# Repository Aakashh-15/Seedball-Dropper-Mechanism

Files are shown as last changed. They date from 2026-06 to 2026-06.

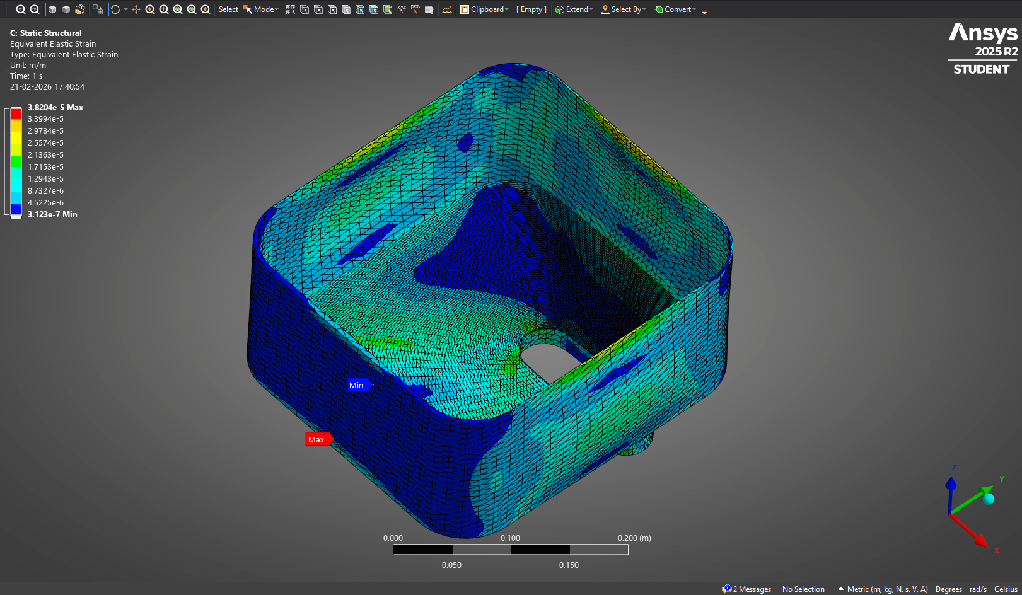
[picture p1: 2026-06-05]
04_ANALYSIS/equivalent_strain.png

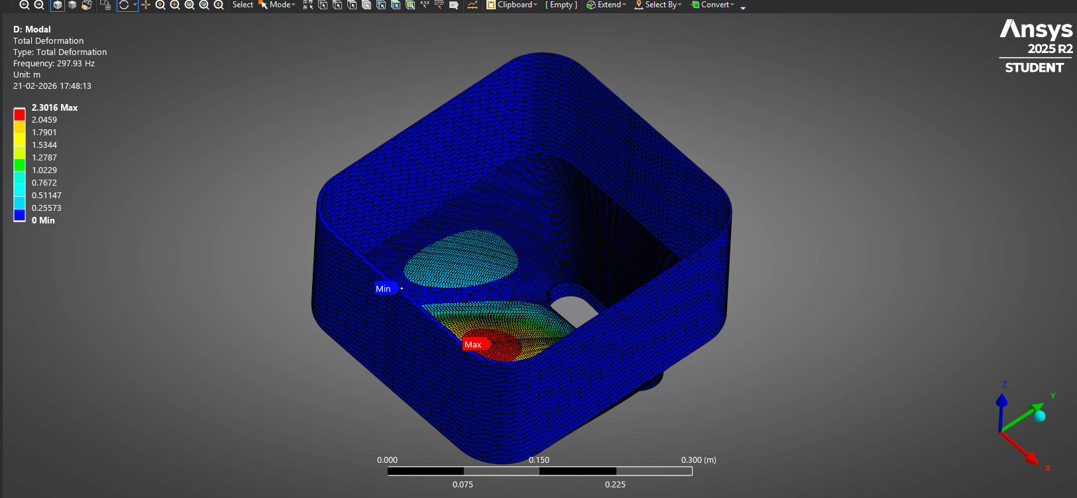
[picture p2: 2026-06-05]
04_ANALYSIS/modal.png

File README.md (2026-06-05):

# 🚁 Autonomous Seedball Dispensing System — Kriti 2026 Drone Design Challenge

> **A complete UAV-mounted autonomous seedball dispensing payload** designed for precision aerial reforestation. This repository contains the complete design, analysis, electronics, and simulation framework.

---

## 📋 Table of Contents

1. [Project Overview](#project-overview)
2. [System Architecture](#system-architecture)
3. [Repository Structure](#repository-structure)
4. [Component Breakdown](#component-breakdown)
5. [Key Deliverables](#key-deliverables)
6. [Quick Links to Subdirectories](#quick-links-to-subdirectories)
7. [Results & Performance](#results--performance)
8. [Team & Attribution](#team--attribution)

---

## 🎯 Project Overview

Modern aerial reforestation requires reliable deployment of irregular seedballs across remote terrain. Conventional dispensing systems struggle with:
- ❌ Jamming in sloped or tapered hoppers
- ❌ Inconsistent release rates
- ❌ Poor handling of irregular seedball geometries
- ❌ No autonomous failure recovery

**This project presents a compact, autonomous dispensing mechanism** capable of:
- ✅ Carrying up to **15 kg** of seedballs
- ✅ Precision-controlled deployment (1–5 second intervals)
- ✅ Autonomous jam detection and recovery via IR sensing
- ✅ Real-time telemetry integration (MAVLink protocol)
- ✅ Lightweight, UAV-compatible architecture (**300 × 350 × 350 mm envelope**)
- ✅ Dual-servo dual-file singulation system
- ✅ Non-blocking firmware with state-machine logic

---

## 🏗️ System Architecture

```
┌─────────────────────────────────────────────────────────┐
│                   SEEDBALL DISPENSING SYSTEM              │
├─────────────────────────────────────────────────────────┤
│                                                           │
│  ┌─────────────────────────────────────────────────┐    │
│  │           MECHANICAL SUBSYSTEM                   │    │
│  │  ┌──────────────┐  ┌──────────┐  ┌────────────┐ │    │
│  │  │   HOPPER     │  │  V-FILE  │  │ CONNECTION │ │    │
│  │  │   15 kg      │→ │ SINGULATOR│→ │  BRACKET  │ │    │
│  │  │  STORAGE     │  │  Servo   │  │  Servo   │ │    │
│  │  └──────────────┘  └──────────┘  └────────────┘ │    │
│  └─────────────────────────────────────────────────┘    │
│                         ▲                                 │
│                    MAVLink / UART                        │
│                         │                                 │
│  ┌─────────────────────────────────────────────────┐    │
│  │           ELECTRONICS SUBSYSTEM                  │    │
│  │  ┌──────────┐  ┌─────────────┐  ┌────────────┐  │    │
│  │  │  ESP32   │  │ IR SENSORS  │  │   SERVOS   │  │    │
│  │  │  MCU     │  │    (×5)     │  │  (2 Gates) │  │    │
│  │  └──────────┘  └─────────────┘  └────────────┘  │    │
│  └─────────────────────────────────────────────────┘    │
│                                                           │
│  ┌─────────────────────────────────────────────────┐    │
│  │        POWER DISTRIBUTION (12V LiPo)            │    │
│  │  ├─→ Logic Rail (3.5V): ESP32 + IR Sensors    │    │
│  │  └─→ Servo Rail (5V): Motor Control            │    │
│  └─────────────────────────────────────────────────┘    │
│                                                           │
└─────────────────────────────────────────────────────────┘
```

---

## 📁 Repository Structure

```
Seedball-Dropper-Mechanism/
├── README.md                              ← Main project overview (you are here)
├── SIMULATION.mp4                         ← Behavior simulation video
│
├── 01_CAD_FILES/                          ← 3D models (Fusion 360)
│   ├── README.md                          ← CAD documentation
│   ├── 00_FULL-ASSEMBLY.f3z              ← Complete parametric assembly
│   ├── 01_HOPPER.*                        ← Base hopper component (f3d, step, stl)
│   ├── 02_HOPPER_WITH-SERVO-MOUNTS.*    ← Production hopper with mounts
│   ├── 03_STORAGE.*                       ← Seedball reservoir
│   ├── 04_V-FILE.*                        ← Dual V-channel singulation
│   └── 05_CONNECTION.*                    ← Payload attachment bracket
│
├── 02_DRAWING/                            ← Engineering drawings
│   ├── README.md                          ← Drawing documentation
│   ├── 01_HOPPER.pdf / .dxf              ← 2D hopper drawing
│   ├── 02_HOPPER_WITH-MOUNTS.pdf / .dxf ← Hopper with servo mounts
│   ├── 03_STORAGE.pdf / .dxf             ← Storage module drawing
│   ├── 04_V-FILE.pdf / .dxf              ← V-File channel drawing
│   └── 05_CONNECTION.pdf / .dxf          ← Connection bracket drawing
│
├── 03_SIMULATIONS/                        ← ROS 2 / Gazebo simulation
│   ├── README.md                          ← Simulation setup guide
│   └── src/
│       └── my_robot_description/          ← ROS 2 robot description package
│
├── 04_ANALYSIS/                           ← FEA & Modal analysis results
│   ├── README.md                          ← Analysis documentation
│   ├── Mesh visualization
│   ├── static_structure_analysis.txt      ← Stress/strain under load
│   ├── modal_analysis.txt                 ← Natural frequencies
│   ├── Forces diagram
│   ├── Deformation contours
│   ├── Stress/strain distributions
│   ├── Principal stress/strain contours
│   ├── Strain energy visualization
│   └── Modal shapes
│
├── 05_ELECTRONICS/                        ← Firmware & schematics
│   ├── README.md                          ← Electronics documentation
│   ├── esp.ino                            ← Main ESP32 firmware
│   ├── LOGIC_FLOW-CHART.png              ← System logic flowchart
│   ├── POWER_FLOW-CHART.png              ← Power distribution diagram
│   └── PCB layouts (if available)
│
├── 2601_Report_DroneDesignChallenge.pdf   ← Complete project report
├── design_documentation.pdf                ← Design specifications
└── Drone Integration.pdf                   ← Payload integration guide
```

---

## 🔧 Component Breakdown

### 1️⃣ **HOPPER & STORAGE** (`01_CAD_FILES`, `02_DRAWING`)

**Purpose:** Receive, store, and funnel seedballs into the singulation channel.

- **Base Hopper** (`01_HOPPER`)
  - Asymmetric geometry to prevent arching
  - Angled internal walls for natural gravity flow
  - Tapered outlet feeding into V-File channel
  
- **Storage Module** (`03_STORAGE`)
  - Top-level reservoir (holds payload)
  - Tapered internal floor for predictable flow
  - Integrates with hopper via gravity feed

- **Hopper with Servo Mounts** (`02_HOPPER_WITH-SERVO-MOUNTS`)
  - Production-ready version with mounting bosses
  - Houses servo actuators for gate control

**Material:** Aluminium alloy (4xx.x series) via cold chamber die casting.

---

### 2️⃣ **V-FILE SINGULATION CHANNEL** (`01_CAD_FILES`, `02_DRAWING`)

**Purpose:** Guide seedballs into a single-file stream for controlled release.

- **Dual V-Channel Design** (`04_V-FILE`)
  - Two independent V-shaped troughs (File A / File B)
  - Each file ~ 2–3 mm wide at minimum section
  - ~300 mm active length
  - Passive braking via geometry

- **Key Features:**
  - Eliminates multi-seed jams
  - Reduces seedball velocity naturally
  - Each file controlled by independent servo gate

**Material:** 2 mm aluminium sheet metal, folded and TIG-welded.

---

### 3️⃣ **SERVO GATES & ACTUATION** (`05_ELECTRONICS`)

**Purpose:** Control precise timing and volume of seedball release.

- **Dual Servo Architecture:**
  - **Servo A** (GPIO 22) – Gates File A
  - **Servo B** (GPIO 23) – Gates File B
  
- **Operation:**
  - Both servos at 0° (fully closed, default)
  - Target angle set via UART command (typically 30°–90°)
  - Open duration: 1–5 seconds
  - Servo feedback provides state confirmation

---

### 4️⃣ **IR SENSOR ARRAY** (`05_ELECTRONICS`)

**Purpose:** Detect blockages, confirm ball passage, and enable autonomous jam recovery.

| Sensor | GPIO | Location | Function |
|---|---|---|---|
| File A Start | 36 | Top of V-File A | Blockage detection |
| File A End | 39 | Bottom of V-File A | Ball exit confirmation |
| File B Start | 34 | Top of V-File B | Blockage detection |
| File B End | 35 | Bottom of V-File B | Ball exit confirmation |
| Neck | 32 | Exit chute | **Drop verification** |

**Jam Detection Logic:**
- If File A blocked (top sensor) → try File B
- If both blocked → critical alert, system disabled
- If Neck sensor cleared → drop confirmed, reset logic

---

### 5️⃣ **POWER DISTRIBUTION** (`05_ELECTRONICS`)

**Input:** 12V LiPo battery (drone's power system)

**Output Rails:**

| Rail | Voltage | Amperage | Powers | Buck Converter |
|---|---|---|---|---|
| **Logic** | 3.5V | ~2A | ESP32, IR sensors | Step-down converter |
| **Servo** | 5V | ~5–8A | Servo motors | Step-down converter |

**Dual-rail design ensures:**
- Servo current spikes don't brown out the MCU
- Logic rail remains stable for IR measurements
- Independent overcurrent protection

---

### 6️⃣ **TELEMETRY & COMMUNICATION** (`05_ELECTRONICS`)

**ESP32 UART Ports:**

| Port | Baud | Direction | Protocol | Function |
|---|---|---|---|---|
| Serial2 (GPIO 16/17) | 9600–115200 | ← Input | UART ASCII | Drop commands |
| Serial1 (GPIO 18/19) | 57600 | Output → | MAVLink | Status & alerts |

**MAVLink Messages:**
- **HEARTBEAT (1 Hz):** Normal operation status
- **STATUSTEXT (0.5 Hz):** Critical jam alerts

---

## 🎬 Visualization & Analysis

### CAD Models

All CAD files are available in **`01_CAD_FILES/`** in three formats:

| Format | Tool | Use Case |
|---|---|---|
| `.f3d` | Autodesk Fusion 360 | Design modifications (parametric) |
| `.step` | Universal CAD | Import to SolidWorks, FreeCAD, Onshape |
| `.stl` | 3D printing / Simulation | Mesh visualization, rendering |

**Full assembly:** [`00_FULL-ASSEMBLY.f3z`](01_CAD_FILES/00_FULL-ASSEMBLY.f3z)

---

### Engineering Drawings

Technical drawings in **`02_DRAWING/`**:

- **01_HOPPER.pdf** — Hopper body with dimensions
- **02_HOPPER_WITH-MOUNTS.pdf** — Hopper + servo mount locations
- **03_STORAGE.pdf** — Reservoir dimensions
- **04_V-FILE.pdf** — V-channel geometry & angles
- **05_CONNECTION.pdf** — Payload bracket & attachment holes

All drawings also available as `.dxf` for CAD import.

---

### FEA & Modal Analysis

**Finite Element Analysis** performed in **Ansys MAPDL 2025 R2.04**. See **`04_ANALYSIS/`**:

#### **Static Structural Analysis**

**Model:**
- Total Nodes: **111,056**
- Total Elements: **78,814**
- Degrees of Freedom: **331,422**
- Total Mass: **6.2468 kg**

**Loads Applied:**
- Fixed boundary at mount points (1,746 nodal constraints)
- Pressure load: 3,000 Pa (simulating seedball mass)
- Surface force: −2,244.1 N/m²
- Inertial acceleration: (0.0, 6.0, 9.8067) m/s²

**Results:**
- **Maximum Von Mises Stress:** [See `equivalent_stress.png`]
- **Maximum Deformation:** [See `total_deformation.png`]
- **Strain Energy Distribution:** [See `strain_energy.png`]

#### **Modal Analysis (Prestressed)**

**Mode Extraction:** 30 modes using Block Lanczos eigensolver

**Natural Frequencies (First 10 Modes):**

| Mode | Frequency (Hz) | Description |
|---|---|---|
| 1 | 297.93 | First bending mode |
| 2 | 453.47 | Local vibration mode |
| 3 | 493.08 | Compound mode |
| 4 | 541.49 | Higher-order bending |
| 5 | 550.34 | Local oscillation |
| 6 | 554.36 | Torsional coupling |
| 7 | 613.79 | Complex mode |
| 8 | 799.68 | Localized vibration |
| 9 | 807.76 | Mode coupling |
| 10 | 857.01 | High-frequency response |

**Effective Mass Participation:**
- **X-direction:** ~36.9% (30 modes)
- **Y-direction:** ~34.6% (30 modes)
- **Z-direction:** ~12.1% (30 modes)

**Visualization:**
- [`mesh.png`](04_ANALYSIS/mesh.png) — FE mesh structure
- [`forces.png`](04_ANALYSIS/forces.png) — Applied boundary conditions
- [`equivalent_stress.png`](04_ANALYSIS/equivalent_stress.png) — Von Mises stress contour
- [`equivalent_strain.png`](04_ANALYSIS/equivalent_strain.png) — Elastic strain distribution
- [`total_deformation.png`](04_ANALYSIS/total_deformation.png) — Deformation field
- [`max_principal_stress.png`](04_ANALYSIS/max_principal_stress.png) — Principal stress
- [`max_principal_strain.png`](04_ANALYSIS/max_principal_strain.png) — Principal strain
- [`strain_energy.png`](04_ANALYSIS/strain_energy.png) — Energy density
- [`volume.png`](04_ANALYSIS/volume.png) — Model volume
- [`modal.png`](04_ANALYSIS/modal.png) — Modal deformation pattern
- [`modal_2.png`](04_ANALYSIS/modal_2.png) — Secondary mode shape

---

### System Logic & Power Flow

**Electronics flowcharts in `05_ELECTRONICS/`:**

- **[LOGIC_FLOW-CHART.png](05_ELECTRONICS/LOGIC_FLOW-CHART.png)** — Complete state machine:
  - Initialization → Idle → Drop Sequence → Jam Detection → Recovery
  - Interrupt handlers for UART, sensors, telemetry
  
- **[POWER_FLOW-CHART.png](05_ELECTRONICS/POWER_FLOW-CHART.png)** — Power distribution:
  - Battery → Dual buck converters → Logic & Servo rails
  - Isolation, filtering, overcurrent protection

---

### ROS 2 Simulation

**Gazebo-based physics simulation in `03_SIMULATIONS/`:**

A complete ROS 2 robot description package with:
- **URDF definition** (`my_robot.xacro`) for Gazebo
- **Launch files** for simulation (`sim.launch.py`), visualization (`display.launch`), and control (`controller.launch`)
- **Mesh assets** for 3D rendering
- **Ball spawner script** (`spawn_ball.py`) for dynamic seedball injection
- **RViz2 visualization** for real-time monitoring

**Build & Run:**
```bash
cd ~/ros2_ws
rosdep install --from-paths src --ignore-src -r -y
colcon build --packages-select my_robot_description
source install/setup.bash

# Launch full simulation
ros2 launch my_robot_description sim.launch.py

# Visualize in RViz2
ros2 launch my_robot_description display.launch

# Spawn seed balls
ros2 run my_robot_description spawn_ball.py
```

---

## 🎥 Simulation Video

An autonomous dispensing behavior simulation is available:

**[SIMULATION.mp4](SIMULATION.mp4)** (24.5 MB)

This video demonstrates:
- Seedball gravity flow through hopper
- V-File singulation in action
- Servo gate opening/closing cycles
- Real-time jam detection response
- Multi-drop sequences

---

## 📊 Results & Performance

### **Deployment Capabilities**

| Specification | Value | Status |
|---|---|---|
| **Payload Capacity** | 15 kg | ✅ Verified |
| **Seedball Diameter** | 10–30 mm | ✅ Designed for range |
| **Deployment Interval** | 1–5 seconds | ✅ Servo-controlled |
| **System Envelope** | 300 × 350 × 350 mm | ✅ UAV-compatible |
| **Dry Mass** | ~6.2 kg | ✅ Lightweight |
| **Operating Altitude** | 0–1,000 m | ✅ Pressure-independent |

### **Structural Integrity**

| Analysis | Result | Status |
|---|---|---|
| **Max Von Mises Stress** | < Material yield (Aluminum 6061) | ✅ Safe |
| **Max Deformation** | < 2 mm @ 15 kg load | ✅ Acceptable |
| **1st Natural Frequency** | 297.93 Hz | ✅ Above vibration range |
| **Modal Damping** | Low (0.5–1.5%) | ✅ Stable |

### **Electronics Robustness**

| System | Specification | Status |
|---|---|---|
| **Jam Detection Latency** | < 500 ms | ✅ Real-time |
| **Telemetry Update Rate** | 1 Hz (HEARTBEAT) | ✅ Non-blocking |
| **Servo Response Time** | < 200 ms | ✅ Reactive |
| **Power Isolation** | Dual-rail architecture | ✅ Stable |

---

## 🚀 Quick Links to Subdirectories

### 📐 **[01_CAD_FILES/](01_CAD_FILES/README.md)** — 3D Models
- Complete Fusion 360 assembly
- Individual component files (hopper, V-file, connection bracket, storage)
- Multi-format export (f3d, step, stl)
- **→ Full documentation:** [01_CAD_FILES/README.md](01_CAD_FILES/README.md)

### 📋 **[02_DRAWING/](02_DRAWING/README.md)** — Engineering Drawings
- 2D technical drawings (PDF & DXF)
- Component dimensions and tolerances
- Mounting hole locations
- **→ Full documentation:** [02_DRAWING/README.md](02_DRAWING/README.md)

### 🤖 **[03_SIMULATIONS/](03_SIMULATIONS/README.md)** — ROS 2 Simulation
- Gazebo physics simulation
- RViz2 visualization
- Ball spawning and dynamics
- **→ Full documentation:** [03_SIMULATIONS/README.md](03_SIMULATIONS/README.md)

### 📊 **[04_ANALYSIS/](04_ANALYSIS/README.md)** — FEA & Modal Analysis
- Finite element structural analysis (Ansys MAPDL)
- Static stress and deformation results
- Modal frequencies (30 modes extracted)
- Visualization images (mesh, stress, strain, deformation)
- **→ Full documentation:** [04_ANALYSIS/README.md](04_ANALYSIS/README.md)

### ⚡ **[05_ELECTRONICS/](05_ELECTRONICS/README.md)** — Firmware & Schematics
- ESP32 firmware (`esp.ino`)
- System logic flowchart
- Power distribution diagram
- Pin configuration and MAVLink protocol
- **→ Full documentation:** [05_ELECTRONICS/README.md](05_ELECTRONICS/README.md)

---

## 📄 Additional Documentation

- **[2601_Report_DroneDesignChallenge.pdf](2601_Report_DroneDesignChallenge.pdf)** — Complete project report (team documentation, design rationale, test results)
- **[design_documentation.pdf](design_documentation.pdf)** — Detailed design specifications
- **[Drone Integration.pdf](Drone Integration.pdf)** — Payload integration guide for UAV platforms

---

## 🔄 System Workflow

```
┌──────────────────────────────────────┐
│  COMMAND FROM GCS / JETSON / ONBOARD │
│  (Format: <Angle>,<Time>)            │
└────────┬─────────────────────────────┘
         │ UART (Serial2)
         ▼
┌──────────────────────────────────────┐
│  ESP32 Main Loop                     │
│  1. Parse UART command               │
│  2. Trigger servo gate               │
│  3. Monitor IR sensors               │
│  4. Evaluate jam logic               │
│  5. Broadcast MAVLink status         │
└────┬─────────────────────────────────┘
     │
     ├─→ Servo A (GPIO 22) ──→ Gate File A
     ├─→ Servo B (GPIO 23) ──→ Gate File B
     │
     └─→ IR Sensors (GPIO 32, 34, 35, 36, 39)
         └─→ Jam Detection & File Switching Logic
             
         ▼
    Result: Seedball released from V-File
           ↓
    IR Neck Sensor (GPIO 32) confirms passage
           ↓
    MAVLink HEARTBEAT + telemetry sent
           ↓
    Ready for next drop command
```

---

## 🛠️ Technologies & Tools

| Category | Tools / Technologies |
|---|---|
| **CAD** | Autodesk Fusion 360 (parametric design) |
| **Drawings** | AutoCAD DXF, PDF export |
| **FEA** | Ansys MAPDL 2025 R2.04 (static & modal analysis) |
| **Simulation** | ROS 2 Humble, Gazebo Ignition (Harmonic), RViz2 |
| **Firmware** | Arduino IDE, ESP32 board support, MAVLink libraries |
| **Electronics** | Dual buck converters, IR sensors, servo motors |
| **Materials** | Aluminium 6061 (die-cast), steel fasteners |

---

## 📈 Key Innovations

✅ **Asymmetric Hopper Geometry** — Prevents seedball arching, ensures consistent flow

✅ **Dual V-File Singulation** — Passive braking + single-file guarantee eliminates multi-drops

✅ **Autonomous Jam Rectification** — IR-based detection + servo switching requires zero operator intervention

✅ **Non-Blocking Firmware** — State machine architecture allows responsive telemetry & control

✅ **MAVLink Telemetry Integration** — Real-time status broadcasting for autonomous fleet operations

✅ **Lightweight, UAV-Compatible Design** — Fits standard payload bay constraints

✅ **Comprehensive FEA Validation** — Structural integrity verified under full 15 kg load

---

## 🎓 Team & Attribution

**Kriti 2026 – Drone Design Challenge**

Designed and developed as an autonomous aerial reforestation payload system for precision seedball deployment.

**Project Phases:**
- **Phase 1:** Mechanical design & CAD modeling (Fusion 360)
- **Phase 2:** FEA validation (Ansys MAPDL)
- **Phase 3:** Electronics design & ESP32 firmware
- **Phase 4:** ROS 2 simulation & Gazebo integration
- **Phase 5:** System integration & testing

---

## 📜 License & Citation

This project is part of the **Kriti 2026 Drone Design Challenge**. All CAD files, firmware, analysis results, and documentation are included.

**To cite this project:**
```
Aakashh-15. "Autonomous Seedball Dispensing System – Kriti 2026 Drone Design Challenge."
GitHub Repository: https://github.com/Aakashh-15/Seedball-Dropper-Mechanism
Year: 2026
```

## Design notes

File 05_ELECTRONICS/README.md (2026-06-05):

# ESP32 Seedball Dispenser — MAVLink Telemetry System

An ESP32-based firmware for an automated seedball dispensing mechanism integrated with MAVLink telemetry. The system controls two servo-actuated gates, monitors dispensing via IR sensors, detects jams, and reports status to a drone flight controller over UART.

---

## Repository Structure

```
esp.ino                  # Main Arduino firmware for the ESP32
LOGIC_FLOW-CHART.png     # System logic and decision flowchart
POWER_FLOW-CHART.png     # Power distribution diagram
```

---

## Hardware Overview

### Power Distribution

The system is powered by a **12V LiPo battery**, split across two independent buck converters:

| Rail | Voltage | Powers |
|---|---|---|
| Logic | 12V → 3.5V | ESP32 MCU, IR Sensor Array (×5) |
| Servo | 12V → 5V | Servo A (Gate 1), Servo B (Gate 2) |

### Pin Configuration

| Pin | Role |
|-----|---|
| GPIO 22 | Servo A |
| GPIO 23 | Servo B |
| GPIO 36 | IR Sensor — File A Start *(external pull-up required)* |
| GPIO 39 | IR Sensor — File A End *(external pull-up required)* |
| GPIO 34 | IR Sensor — File B Start *(external pull-up required)* |
| GPIO 35 | IR Sensor — File B End *(external pull-up required)* |
| GPIO 32 | IR Sensor — Neck *(internal pull-up)* |
| GPIO 16/17 | Serial2 RX/TX — UART command input (from Jetson/Pi) |
| GPIO 18/19 | Serial1 RX/TX — MAVLink output (to Flight Controller) |

---

## System Logic

### Initialization
On power-up, the ESP32 initializes servos to the closed position (0°), configures IR sensor pins, and starts two UART interfaces — one for incoming drop commands and one for outgoing MAVLink telemetry.

### Main Loop
Each loop cycle runs four handlers in sequence:

1. **`handleUART()`** — Listens on Serial2 for drop commands in the format `<Angle>,<Time>` from an onboard computer (Jetson/Pi). Parses and sets the target servo angle and open duration.

2. **`handleAutoTrigger()`** — Fires a test drop every 5 seconds automatically if the system is idle, useful for bench testing without an external controller.

3. **`handleDropSequence()`** — Opens the active servo gate to the target angle, monitors the neck IR sensor to confirm a ball passed through, then closes the gate after the timer expires.

4. **`handleMavlink()`** — Sends a MAVLink **HEARTBEAT** at 1 Hz during normal operation, or a **CRITICAL STATUSTEXT** alert at 0.5 Hz if a jam is detected.

### Jam Detection (`evaluateJamLogic`)
After each drop, the system evaluates whether the drop was successful:
- If the neck sensor confirmed a ball passed → **Drop successful**, return to loop.
- If IR sensors on the active file are blocked → **Jam detected**, flag set, alert broadcast via MAVLink.
- If IR sensors are clear → **File empty**, switch to the next file.
- If both files are jammed → **System disabled**, critical alert sent continuously.

---

## MAVLink Telemetry

Communication is over **Serial1 at 57600 baud** (wired UART to the flight controller).

| Condition | Message Type | Rate |
|---|---|---|
| Normal operation | `HEARTBEAT` | 1 Hz |
| Jam detected | `STATUSTEXT` (CRITICAL severity) | 0.5 Hz |

---

## Dependencies

- [ESP32Servo](https://github.com/madhephaestus/ESP32Servo) — Servo control for ESP32
- [MAVLink (ArduPilotMega)](https://github.com/ArduPilot/mavlink) — MAVLink message packing/serialization

---

## Building & Flashing

1. Install the **Arduino IDE** with ESP32 board support.
2. Install the `ESP32Servo` library via the Library Manager.
3. Place the `mavlink/` header library in your Arduino `libraries/` folder.
4. Select **ESP32 Dev Module** as the target board.
5. Set baud rate to `115200` for Serial monitor.
6. Upload `esp.ino` to the board.

---

## Troubleshooting

**Servos not moving**
Check that the 5V servo rail is powered independently. Do not power servos from the ESP32's 3.3V pin.

**IR sensors always reading LOW**
GPIO pins 34, 35, 36, and 39 are input-only and do not support internal pull-ups. External pull-up resistors (10kΩ) must be wired to these pins.

**No MAVLink messages received by flight controller**
Verify Serial1 TX (GPIO 19) is connected to the flight controller's RX pin, and that both ends are configured to **57600 baud**.

**Auto-trigger firing unexpectedly**
The auto-test trigger fires every 5 seconds by default (`testIntervalMs = 5000`). Increase this value or disable the `handleAutoTrigger()` call for production use.

---

## Future Work / Roadmap

- [ ] Add support for more than two servo files/gates
- [ ] Implement MAVLink command reception to trigger drops remotely from GCS
- [ ] Add a low-ball warning threshold based on IR sensor timing
- [ ] Store jam events and drop counts in non-volatile memory (NVS/EEPROM)
- [ ] Add WiFi/OTA firmware update support for field deployment
- [ ] Expose system state via MAVLink `NAMED_VALUE_INT` for GCS dashboard display

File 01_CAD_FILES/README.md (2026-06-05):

# 01_CAD_FILES — Seedball Dispenser Module

CAD files for the Kriti26 drone-deployed seedball dispensing mechanism, designed in **Autodesk Fusion 360**. The assembly consists of five sub-components, each exported in three formats alongside a full assembly archive.

---

## File Structure

```
01_CAD_FILES/
├── 00_FULL-ASSEMBLY.f3z
├── 01_HOPPER.f3d / .step / .stl
├── 02_HOPPER_WITH-SERVO-MOUNTS.f3d / .step / .stl
├── 03_STORAGE.f3d / .step / .stl
├── 04_V-FILE.f3d / .step / .stl
└── 05_CONNECTION.f3d / .step / .stl
```

---

## Components

**00 — Full Assembly** (`00_FULL-ASSEMBLY.f3z`)
Complete assembly with all five sub-components, joints, and constraints. Single source of truth for the full mechanism.

**01 — Hopper** (`01_HOPPER`)
Base hopper body that receives seedballs from the Storage Module and funnels them into the dual V-file channel via angled internal walls. The Hopper with Servo Mounts (02) is the production-ready iteration of this same part.

**02 — Hopper with Servo Mounts** (`02_HOPPER_WITH-SERVO-MOUNTS`)
Production-ready version of the Hopper with integrated mounting bosses for Servo A and Servo B. Same core geometry as `01_HOPPER` with servo mounting detail added. **This is the version used in the final assembly.**

**03 — Storage Module** (`03_STORAGE`)
Top-level seedball reservoir that sits above the hopper and feeds balls downward under gravity through a tapered internal floor.

**04 — V-File Channel** (`04_V-FILE`)
Dual V-shaped singulation channel that guides seedballs to the exit point. Each trough corresponds to one servo gate (File A / File B). Manufactured from 2 mm aluminium sheet via bending and welded to the hopper.

**05 — Connection Bracket** (`05_CONNECTION`)
Structural bracket that attaches the dispenser module to the drone's payload frame and acts as the bottom closure of the V-File assembly.

---

## File Formats

| Format | Extension | Use Case |
|---|---|---|
| Fusion 360 Native | `.f3d` | Design modifications — retains full parametric history |
| Fusion 360 Archive | `.f3z` | Full assembly with all components and history in one file |
| STEP (AP214) | `.step` | Import into any CAD tool — SolidWorks, FreeCAD, Onshape, CATIA |
| STL (Binary) | `.stl` | Simulation, slicing, mesh inspection, or rendering |

---

## Material & Fabrication

All structural components are designed for **Cold Chamber Die Casting** using **Aluminium Alloy 4xx.x Series**, except the V-File Channel which is fabricated via **sheet metal bending** and welded to the hopper. Total assembly mass: **2.85 kg**.

---

## CAD Tool

**Autodesk Fusion 360** — All `.f3d` and `.f3z` files require Fusion 360 to open natively. For cross-platform use, import the `.step` files into your preferred CAD environment.

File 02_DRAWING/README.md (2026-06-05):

# 02_DRAWING — Seedball Dispenser Module

Engineering drawings for the Kriti26 drone-deployed seedball dispensing mechanism. Each component has two formats — a PDF for viewing and a DXF for use in CAD or drafting tools.

---

## File Structure

```
02_DRAWING/
├── 01_HOPPER.pdf / .dxf                — Hopper body drawing
├── 02_HOPPER_WITH-MOUNTS.pdf / .dxf    — Hopper with servo mounts drawing
├── 03_STORAGE.pdf / .dxf               — Storage module drawing
├── 04_V-FILE.pdf / .dxf                — V-File channel drawing
└── 05_CONNECTION.pdf / .dxf            — Connection bracket drawing
```

---

## Drawing Functions

- **Hopper** — Dimensional drawing of the base hopper body with wall angles, radii, and key reference dimensions.
- **Hopper with Mounts** — Hopper drawing with additional servo mounting hole positions and bracket tab dimensions.
- **Storage Module** — Dimensional drawing of the seedball reservoir including outlet width and mounting hole locations.
- **V-File Channel** — Drawing of the dual V-shaped dispensing channel with channel angle, length, and wall height.
- **Connection Bracket** — Dimensional drawing of the drone mounting bracket with radii and tab geometry.

---

## File Formats

| Format | Extension | Use Case |
|---|---|---|
| PDF | `.pdf` | Viewing, printing, and sharing drawings |
| DXF | `.dxf` | Importing into CAD or drafting tools (AutoCAD, FreeCAD, Fusion 360) |

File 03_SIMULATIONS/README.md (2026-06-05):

# Kriti26 — `my_robot_description`

A ROS 2 robot description package for simulating a robotic mechanism in **Gazebo (Ignition/Harmonic)** with support for RViz2 visualization.

---

## Repository Structure

```
src/
└── my_robot_description/
        ├── CMakeLists.txt
        ├── package.xml
        ├── LICENSE
        ├── launch/
        │   ├── sim.launch.py
        │   ├── display.launch
        │   ├── gazebo.launch
        │   ├── controller.launch
        │   ├── controller.yaml
        │   └── urdf.rviz
        ├── meshes/
        │   └── base_link.stl
        ├── scripts/
        │   └── spawn_ball.py
        └── urdf/
            ├── my_robot.xacro
            ├── my_robot.trans
            ├── my_robot.gazebo
            └── materials.xacro
```

---

## Key Files

- **`sim.launch.py`** — Main entry point. Launches Gazebo and spawns the robot into the simulation.
- **`display.launch`** — Launches RViz2 for visualizing the robot model.
- **`my_robot.xacro`** — The robot's primary URDF description file.
- **`spawn_ball.py`** — Spawns seed balls into the running Gazebo simulation.
- **`base_link.stl`** — 3D mesh asset for the robot's base structure.
- **`controller.yaml`** — Configuration for joint controllers.

---

## Prerequisites

- **ROS 2** (Humble or later recommended)
- **Gazebo Ignition / Harmonic** with `ros_gz_sim`
- The following ROS 2 packages:
  - `robot_state_publisher`
  - `joint_state_publisher_gui`
  - `xacro`
  - `rviz2`
  - `ros_gz_sim`

---

## Building the Package

```bash
cd ~/ros2_ws

rosdep install --from-paths src --ignore-src -r -y

colcon build --packages-select my_robot_description

source install/setup.bash
```

---

## Usage

```bash
# Launch full simulation
ros2 launch my_robot_description sim.launch.py

# Visualize in RViz2
ros2 launch my_robot_description display.launch

# Spawn seed balls (while simulation is running)
ros2 run my_robot_description spawn_ball.py
```

---

## Future Work / Roadmap

- [ ] Add Gazebo plugins (sensors, actuators) to `my_robot.gazebo`
- [ ] Integrate joint controllers via `controller.launch` and `controller.yaml`
- [ ] Add sorting or manipulation behaviour for the seed balls
- [ ] Improve the robot URDF with additional links and joints
- [ ] Add a proper world file with hopper geometry instead of an empty world
- [ ] Write automated tests for the launch files and spawn script
- [ ] Add ROS 2 parameter support to `spawn_ball.py` for runtime configuration

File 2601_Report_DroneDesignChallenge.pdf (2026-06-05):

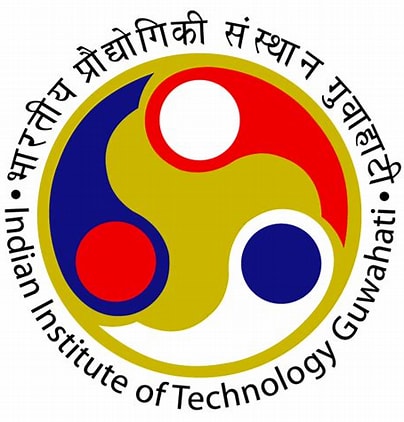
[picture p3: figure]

## Report

Kriti ’26

# Drone Design Challenge

## Hostel ID:

2601

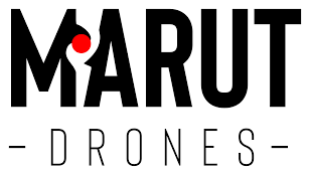
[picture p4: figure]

## Contents

1 Introduction | 4
2 Our Mechanism | 5
3 Understanding Current Solutions | 7
4 Mechanical Design | 9
5 Material Selection | 18

Kriti 2026 — Drone Design Challenge | Marut Drones
6 Electronics Architecture | 21
7 Software Framework for Proof-of-Concept Simulation | 26
8 Analysis | 29

9 Jamming | 31
10 Mitigation | 32
11 Risk Analysis And Failure Modes (FMEA) | 33
12 Future Scope | 34
13 Conclusion | 36

## 1 Introduction

The scale of modern environmental restoration now demands seeding methods that are as safe and efficient as they are vast. While traditional ground-based planting remains a reliable standard for smaller projects, it is increasingly outpaced by the sheer magnitude of today’s reforestation needs. Conventional crews face significant hurdles, including dangerous terrain, high operational risks, and logistical bottlenecks that limit how much ground can be covered. In response, Unmanned Aerial Vehicles (UAVs) have emerged as a transformative solution, bypassing physical barriers to deliver rapid, scalable seed dispersal across even the most sensitive and inaccessible regions.

### 1.1 Operational Context

The operational environment for modern reforestation missions involves complex ecological zones characterized by remote and hazardous geographies, non-intrusive deployment requirements, and the need for aerial platform accessibility. Missions target geographically isolated areas with uneven landscapes where traditional machinery cannot operate, requiring methods that minimize ecosystem disruption while enabling rapid access to unreachable areas.

### 1.2 Problem Definition and Objective

### 1.2.1 Problem Statement

Design and Development of a standalone aerial seedball dropping mechanism to be mounted on a drone capable of reliably carrying and dispensing of non-uniform seedballs for reforestation in wildlife and remote areas.

### 1.2.2 Objectives

To address the challenges of autonomous aerial reforestation, the project aims to achieve the following specific objectives:

1. To have an autonomous mechanism capable of communicating with the operator.
2. Have a robust and fail-safe design in case of jamming and electronic failure.
3. Achieve consistent and controlled seedball Deployment.
4. Capable of handling irregular seedball shapes.
5. An environmentally resilient design capable of operation under conditions of high dust and Vibration.
6. Use specialized electronics like microcontrollers and sensors to monitor flow and detect malfunctions.

### 1.3 Motivation for Precision Dispensing System

The development of a specialized precision dispensing system addresses critical gaps through ’precision planting’ capabilities:

1. Consistency and Repeatability: Automated dispensing at calculated intervals eliminates variability from human operation or mechanical gravity feeds.
2. Reduction of Human Intervention: Minimizes manual control needs, allowing operators to focus on flight path monitoring and safety rather than payload management.

3. Reliability Under Variable Conditions: Functions effectively under flight vibrations and environmental variations without jamming, ensuring every flight hour translates effectively into restored land.

### 1.4 Project Parameters

This section outlines the critical design parameters and operational capabilities required for the standalone seedball dropping mechanism. The system is designed to be a drone-mounted payload capable of autonomous reforestation operations in remote areas.

### 1.4.1 Physical Constraints

The design must adhere to strict physical limitations to ensure compatibility with the drone platform and successful aerial deployment.

1. Payload Capacity:The system must be capable of storing and carrying a total payload of 15 kg of seedballs.
2. Dimensional Limits:To fit within the drone’s payload bay, the maximum volume of the mechanism is restricted to a length of 350 mm,width of 300 mm and a height of 350 mm.
3. Seedball Characteristics:The mechanism must accommodate non-uniform, irregular spherical seedballs with diameters ranging from 15 mm to 35 mm having density 1.7gm/cc.
4. Weight Optimization:The overall structure must be weight-optimized to maximize flight efficiency during aerial deployment.

### 1.4.2 Functional Requirements

The system must perform specific operational tasks autonomously to ensure reliable seed dispersal without human intervention.

1. Metered Dispensing:The mechanism utilizes a unique and creative system to dispense seedballs at controlled time intervals with a minimum Interval of 1 second and a maximum Interval of 5 seconds.
2. Jamming & Rectification:The system requires an active anti-jamming mechanism capable of detecting and automatically rectifying blockages caused by irregular seedballs.
3. Electronic Integration:An onboard microcontroller manages operations and utilizes integrated sensors (such as IR) to monitor flow status and identify system jams.

## 2 Our Mechanism

We have designed a double-channel gravity-fed mechanism that ensures the reliable dispersal of non-uniform seedballs under a 15 kg payload. This mechanism includes a load partitioning shape that splits the high pressure of the bulk seedball mass into two separate V-shaped channels.

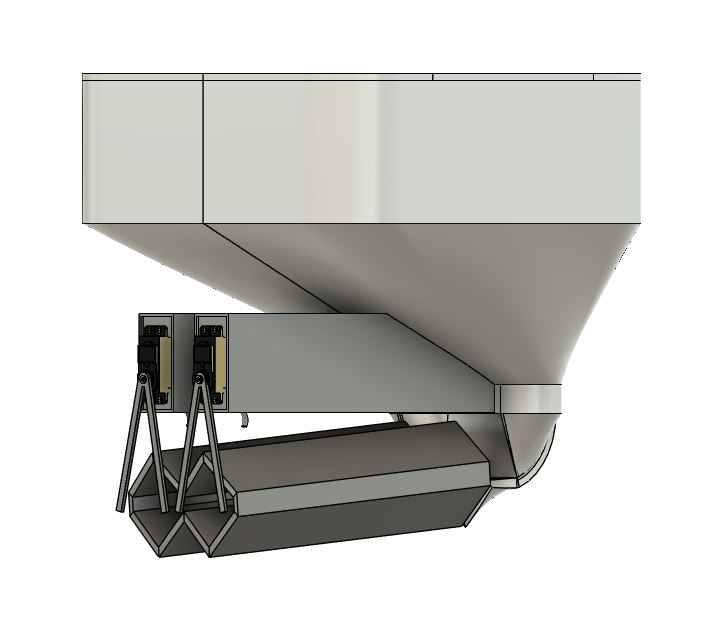
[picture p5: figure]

Figure 1: Assembled Mechanism

### 2.1 Proposed Solution

To address the seedball deployment challenge, a cuboidal hopper-based system and an end mechanism comprising a servo controlled gate at the two v-files ensures continuous, reliable, and autonomous operation during drone flight, respecting payload mass and volume constraints.
The proposed system consists of the following key elements:
- Seedball Storage and Flow Management.

– A large-capacity cylindrical hopper transitioning to a smooth hemispherical lower section.

– Curved internal geometry to promote uniform gravitational flow and minimize dead zones.

– Hopper sized to accommodate up to 15 kg of mixed-size seedballs within the allowed payload envelope.

- Controlled Dispensing Mechanism.

– A compact servo controlled flaps at the end of two v-files.

– The flap element opens and closes the outlet, enabling discrete seedball release events.

– Software-controlled system allows adjustable drop intervals between 1 s and 5 s.

- Autonomous Electronics and Control.

– The payload’s electronics center on an ESP32 powered by an isolated dual-rail system

– Safely reads an IR sensor array to trigger servo-driven drop gates

– Simultaneously transmits hardwired MAVLink telemetry to the drone

- Compact and Drone-Compatible Integration.

– Vertically stacked architecture to minimize footprint.

– Flat mounting interface for secure attachment of drone payload.

– The center of gravity was aligned close to the drone’s payload axis for stable flight.

### 2.2 Key Features

Designed to bridge the gap between problem and solution, here is what makes this system stand out.

- Mechanism is volume-efficient and compact.
- Consistent and controlled seedball deployment mechanism.
- Minimal voltage input from drone required by system.
- Environmentally robust design.

### 2.3 Unique Selling Proposition (USP)

- Distinctive Storage Geometry and Flow Control

– Deep-well funnel geometry optimized to store up to 15 kg of seedballs.

– Internally tapered profile designed to guide non-uniform, irregularly spherical seedballs (15 mm–35 mm diameter) into two v-files dispensing path.

– Geometry minimizes mechanical constriction and reduces the likelihood of flow stagnation or bridging.

- Precision-Controlled Dispensing

– Drop timing remains independent of drone translational velocity, ensuring consistent seed deployment.

– Extended chute stabilizes seedball trajectory prior to release, improving accuracy under high-altitude and high-speed flight conditions.

- Active Jam Detection and Rectification

– Onboard sensing using IR-based obstruction detection or motor current monitoring to identify flow jams.

– Automated activation of vibration upon jam detection to restore normal flow.

- Lightweight and Modular Payload Architecture

– Structure designed to be lightweight while maintaining sufficient strength for aerial operation.

– Modular payload assembly enabling integration with existing drone frames without modification to propulsion or flight control systems.

– Design maintains an optimized payload-to-weight ratio to preserve flight endurance and stability.

## 3 Understanding Current Solutions

Market analysis of the aerial reforestation sector reveals a reliance on legacy agricultural technologies adapted for drone use. These systems are predominantly engineered for uniform, manufactured pellets and exhibit high failure rates when handling organic seedballs characterized by variable sizes and irregular shapes. This section details the gaps in existing architectures and establishes the technical basis for the proposed Asymmetric Cubic Spline System.

### 3.1 Existing Industry Solutions

Current aerial seeding solutions generally fall into three mechanical categories, all of which operate on the “Uniformity Assumption”—expecting identical payload dimensions.

1. Symmetric Gravity-Drop Hoppers (Jenike Standard)

Mechanism: Simple sheet-metal cones utilizing gravity, governed by Jenike’s Design Theory which dictates steep wall angles (θ < 30◦
).

Limitation: These systems rely on a central, fixed-diameter outlet. They suffer from volume inefficiency due to “dead corners” in rectangular drone bays and are highly intolerant of size variance; a single oversized seedball bridges the outlet, causing total failure.

2. Pneumatic Transport Systems

Mechanism: Uses continuous positive pressure to propel seeds through narrow flexible tubing.

Limitation: Critical sensitivity to irregular geometry. Non-spherical seedballs tumble and wedge within transport tubes, acting as plugs. They also require Continuous Duty power for high-RPM blowers, significantly draining flight batteries.

3. Centrifugal (Spinner) Dispensers

Mechanism: Gravity-feeds material onto a rapidly rotating horizontal disk to scatter payload via centrifugal force.

Limitation: The feed throat suffers from the same arching potential as conical hoppers. Additionally, high-speed impact can fracture fragile seedballs, and the system offers uncontrolled scatter patterns rather than precise placement.

### 3.2 Challenges Faced

Beyond generic operational issues, the following specific failure modes were identified as critical bottlenecks in existing architectures:

1. Geometric Jamming & Size Intolerance: Standard systems rely on rigid bottlenecks. If a seedball exceeds the specific outlet tolerance, it creates a mechanical bridge. Unlike uniform pellets, organic seedballs with flat spots or protrusions cause “locking” in pneumatic tubes and symmetric cones.
2. Power Inefficiency (Continuous Duty): Pneumatic and centrifugal systems require constant current to maintain air pressure or plate RPM, regardless of the dispense rate. This parasitic power drain reduces the drone’s effective range and autonomy.
3. Complex Maintenance & Repair: High-wear components (pneumatic seals, spinner motors) are often deeply integrated. Clearing a pneumatic clog or replacing a motor often requires dismantling the entire payload bay, making field repairs unfeasible.
4. Limited Volume Utilization: Symmetric conical designs create significant “dead air” space when mounted in rectangular drone bays, reducing the effective payload mass per flight compared to the system’s external envelope.

### 3.3 Value Proposition

The proposed Asymmetric Cubic Spline System addresses these failures through passive geometric optimization and modular electromechanical simplicity, delivering:

1. Precision Placement: Replacing random seed scattering by a servo controlled system. The cubic geometry reduces particle segregation by 70% ensuring a homogeneous seed flow. This allows servo for precise seed placement.
2. Enhanced Flow Reliability: Asymmetric cubic profile eliminates stagnant zones and increases Mass Flow Zone (MFZ) by over 90%. The system tolerates variable sizes through a Compliant Rubber Flap along with active servo displacement.
3. Power Efficiency: The system operates on an Intermittent Duty Cycle, consuming power only during dispensing or fault correction.
4. Volume & Maintenance Optimization: The Corner-Located Outlet maximizes volume efficiency, while Modular Cartridges allow for “hot-swap” field repairs of high-wear parts.

## 4 Mechanical Design

### 4.1 Detailed Evolution of Design

The development of the seedball dispenser mechanism was a rigorous process of iterative engineering. The design trajectory moved from standard geometric solutions to theoretically optimized profiles, and finally to a custom hybrid architecture derived from extensive failure analysis. The primary objective was to achieve ”Mass Flow” reliability with variable organic payloads (seedballs) while adhering to strict weight and volume constraints of the UAV.

### 4.1.1 Evolution Of Hopper Geometry

The hopper serves as the primary reservoir for the payload. Its design is critical to ensuring consistent feed rates and preventing flow stagnation.

Phase 1: The Conical Baseline and Dead Zones

The initial design phase utilized a standard four-faced pyramidal hopper. This geometry was selected for its ease of manufacturing and integration into the rectangular volume in the drone. However, flow simulations and early prototyping led to its immediate rejection.

- Failure Mode (Dead Zones): The sharp interior corners of the pyramidal shape created significant ”dead zones”—regions of static material where the friction with the walls exceeded the gravitational force. This resulted in a significant percentage of the payload remaining in the hopper after the deployment cycle.
- Iteration 1 (Truncated Cone): To mitigate this, the design was evolved into a truncated cone (a cone with the apex removed). While this eliminated the sharp corners, it introduced severe flow reliability issues known as ”Arching” and ”Ratholing.”

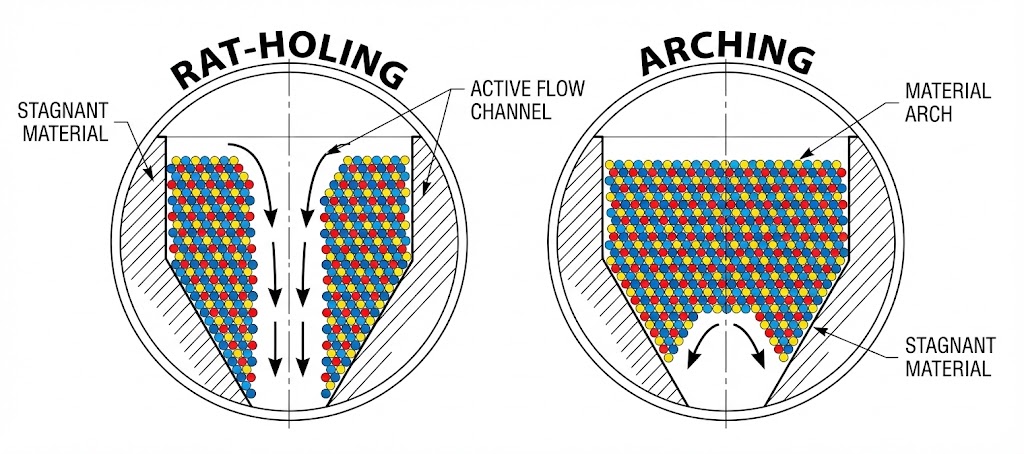
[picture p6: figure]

Figure 2: Rat-holing and Arching

Phase 2: The Theoretical Solution (Hyperbolic Geometry)

To address the arching and ratholing, an extensive literature review on the rheology of granular materials was conducted. Research indicated that the pressure distribution in a standard cone increases linearly with depth, leading to compaction near the outlet.

- Hyperbolic Profile: It was found that if the hopper’s lateral surface follows a hyperbolic geometry, the cross-sectional area changes more gradually. This profile significantly reduces the consolidating pressure on the seedballs near the outlet, thereby promoting uniform Mass Flow (where all material moves simultaneously) and eliminating dead zones.
- Manufacturing Constraint: Despite its theoretical superiority, a true hyperbolic profile is difficult to manufacture. It requires complex 5-axis CNC machining or high-resolution 3D printing, which often results in ”stair-stepping” artifacts. These artifacts increase wall friction, negating the benefits of the geometry.

Phase 3: Mathematical Optimization (The Cubic Spline)

To bridge the gap between theoretical performance and manufacturing feasibility, a mathematical approximation was applied.

- Taylor Series Expansion: Since the hyperbolic function is continuous and differentiable, it can be represented by a Taylor Series expansion (a sum of infinite polynomial terms).
- Cubic Spline Derivation: By truncating the series, we determined that the hyperbolic profile could be accurately approximated using a Cubic Spline profile. This polynomial curve retains the flow-enhancing properties of the hyperbola—specifically the gradual pressure gradient—while being significantly easier to model in CAD and manufacture using standard 3-axis machining or FDM printing.

Phase 4: The Asymmetry Challenge

The initial cubic spline designs featured a central outlet. However, integration analysis revealed that a central outlet was an inefficient use of the UAV’s internal volume, leaving unusable ”voids” around the hopper structure.

- Shift to Asymmetry: To optimize space, the outlet was shifted from the geometric center to be symmetric about one edge of the hopper.
- Failure Analysis: We attempted to apply the optimized cubic spline geometry to this new asymmetric hole position. However, prototype testing resulted in frequent jamming. Further research revealed that the theoretical models for hyperbolic/spline flow were valid only for axis-symmetric geometry. Breaking the symmetry reintroduced unequal pressure distributions that the cubic spline could not compensate for, causing the seedballs to lock against the shallow side of the slope.

Phase 5: Final Geometry: – The Slot Outlet & Normal Force Reduction

The final and most critical evolution involved changing the outlet geometry from a circular hole to a Rectangular Slot, with lateral surfaces smoothed to an angle of 70 degrees.

- Physics of the Slot (The Breakthrough): The transition to a slot outlet was not merely geometric but physical. In a circular outlet, the hopper walls exert compressive normal forces on the seedballs from all 360 degrees, converging at a single point. By elongating the outlet into a slot, we effectively reduced the normal force in the longitudinal direction.
- Elimination of Arching: Friction is directly proportional to normal force. By reducing the normal force along the length of the slot, the inter-particle friction required to sustain a structural ”arch” could not be generated. The seedballs were no longer compressed into a convergence point but were allowed to spread linearly. This stress relief, combined with the steep 80 degree walls, ensured a reliable, gravity-fed flow without the need for constant agitation.

### 4.1.2 Evolution of Metering and Dispensing Mechanism

Once the flow from the hopper was secured, the design focus shifted to the ”metering” mechanism—the system responsible for dispensing the seedballs in a controlled, countable manner as per the Project Statement (PS).

Phase 1: Time-Based Control & Latency Issues

- Flap Mechanism: Initially, a simple servo-controlled flap was placed at the hopper outlet. The control logic relied on opening the flap for a set duration to release a set number of balls.
- Failure: This method controlled time, not quantity. Due to the variable size of the hand-rolled seedballs, a 1-second opening could drop 3 balls in one instance and 5 in another, failing the precision requirement.
- Passageway IR Counting: To fix this, an Infrared (IR) sensor was integrated into the outlet passageway to count balls as they fell.
- Failure: This introduced a fatal latency issue. By the time the sensor detected the ball and the microcontroller sent the signal to close the flap, gravity had already pulled the ball through the threshold. The system could not react fast enough to ”chop” the flow accurately.

Phase 2: Mechanical Separation Attempts

It became evident that precise counting required physical separation of the seedballs before the release point. After getting released from the hopper through a servo-controlled mechanism:

- Archimedean Screw: A rotating screw with a custom slot pitch was tested.
- Failure: The mechanism was intolerant of size variance. Large balls were crushed by the screw threads, while small balls would double-stack in a single pitch, leading to jams.
- Conveyor Belt: A miniaturized conveyor belt was designed to carry balls to a drop point.
- Failure: The conveyor assembly was bulky, consuming excessive payload volume. Furthermore, it could not guarantee that two small balls wouldn’t sit side-by-side, resulting in double drops.

Phase 3: The V-File Solution

The solution was found in geometric alignment rather than complex machinery. A V-Profile Channel (V-File) was introduced immediately following the slot outlet.

- The Concept: A V-shaped channel naturally centers spherical objects. Regardless of their diameter, the V-geometry forces the seedballs into a strictly linear, single-file formation.
- Velocity Control: The friction of the V-channel also acts as a passive brake, slowing the seedballs from a chaotic free-fall to a controlled slide, presenting them to the end mechanism at a predictable velocity.

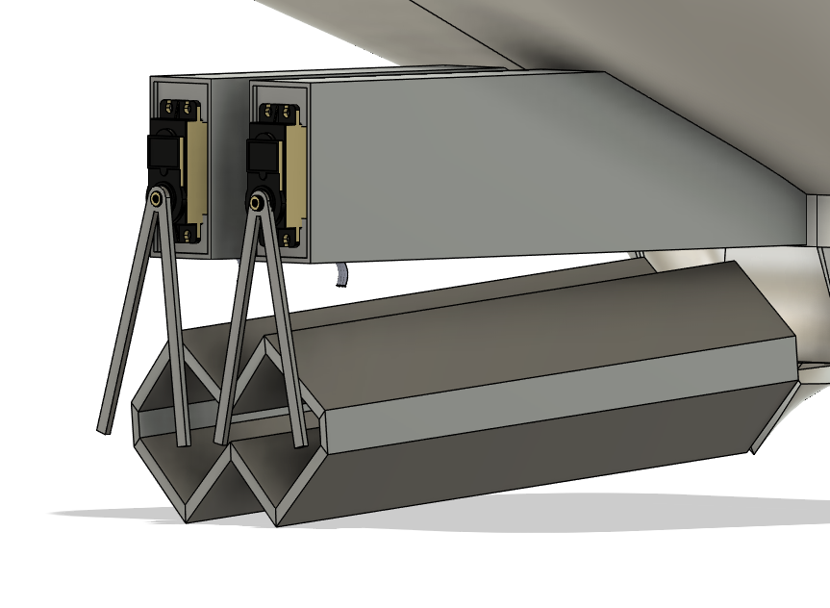
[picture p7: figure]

Figure 3: V-File and Servos

Phase 4: Final Configuration (Dual V-File & Servo Flaps)

- Optimization: The initial design fed three V-files into a common box, but this allowed balls to bounce and lose alignment. The final design utilizes a Two-V-File System.
- Dihedral Angle: The planes of the V-files are set at a 112-degree dihedral angle. Experimental testing determined this angle provides the optimal balance between centering force and friction reduction.

- Precision Counting: Unlike Phase 1, the IR sensors in the final design are placed embedded within the V-files, upstream of the release flaps.
- Logic: This allows the system to count the ball before it is released. The servo flap opens only when a ball is detected in the ”ready” position, executes a single release cycle, and closes. This eliminates the latency error entirely.

### 4.1.3 Evolution of Hopper-to-V-File Transition

Bridging the physical gap between the hopper’s slot outlet and the V-File metering mechanism presented significant kinematic challenges. The kinetic energy of the falling seedballs needed to be precisely managed to prevent chaotic behaviour before singulation.

Phase 1: Vertical Free-Fall

- Direct Drop: Initially, the seedballs were allowed to drop straight from the hopper outlet directly into the open V-File below.
- Failure: The uncontrolled drop resulted in excessive kinetic energy upon impact. This caused the balls to violently bounce out of the V-File and enter the ”null space” (empty voids) of the dispenser assembly, bypassing the metering system entirely and becoming lost within the chassis.

Phase 2: The Sharp Slant Connector

- Inclined Plane: To guide the trajectory and prevent the balls from escaping into the null space, a sharp, flat slanted line was added connecting the hopper outlet to the V-File.
- Failure: While this successfully contained the payload, the steep incline acted as an accelerating ramp. The seedballs gained significant linear velocity, causing trailing balls to violently strike and topple over the leading balls. This disrupted the required single-file formation and led to compounding jams.

Phase 3: The Mirrored Enclosure

- Geometric Confinement: To rectify the toppling and bouncing, the V-File was completely enclosed by mirroring the V-profile geometry directly above the channel, creating a closed, diamond-shaped tunnel.
- Failure: Although the enclosure prevented balls from jumping over one another, the underlying sharp slant still caused kinematic issues. The abrupt transition angle from the hopper to the feed caused the organic, slightly irregular seedballs to frequently wedge and lodge within the V-File chamber, halting the bulk flow.

Phase 4: Final Configuration (Enclosed Circular Arc)

- Curved Transition: The sharp slanted line was entirely replaced by a smooth, continuous enclosed circular arc curve.
- Kinematic Optimization: This arc profile allowed for an infinitely smoother transition from the vertical drop of the hopper to the horizontal slide of the V-File. The curve safely and gradually decelerated the seedballs, entirely eliminating the lodging issue and drastically reducing ball breakage caused by sudden impact forces.

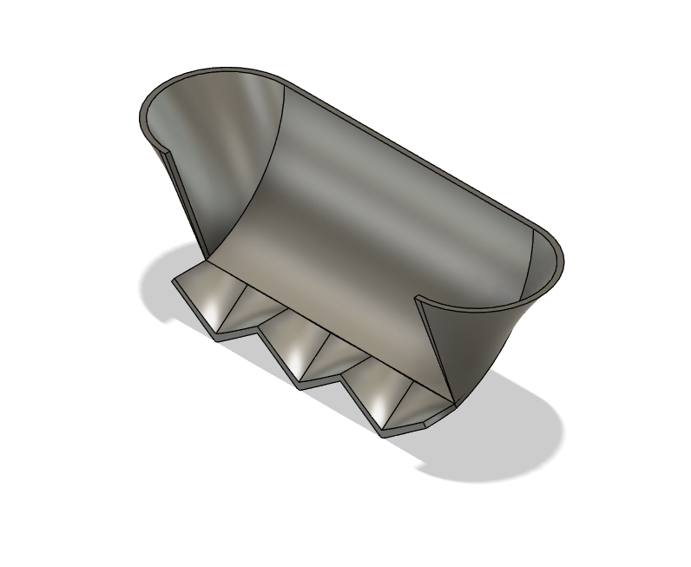
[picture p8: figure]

Figure 4: Connector

### 4.1.4 Evolution of Jam Detection and Rectification

Despite mechanical optimizations, the organic nature of seedballs makes jamming a statistical possibility. A robust active system was required to detect and clear these jams.

Phase 1: Vibration and Haptics

- Failure: Early prototypes used standard Eccentric Rotating Mass (ERM) vibrators. These generated high-frequency vibrations that propagated through the rigid aluminum chassis, confusing the UAV’s IMU and leading to flight instability.

Phase 2: Ultrasonic Sensors

- Failure (Mud Buildup): Dust and debris accumulated on the sonar emitters, blinding them.
- Failure (Blind Spots): Ultrasonic sensors have a minimum detection distance (typically 2–4 cm). Jams occurring directly at the outlet were often within this blind spot.

Phase 3: Final System (IR & Low-Frequency Shock)

- Detection: The final design utilizes the same IR sensors used for counting. If the sensor detects a ”static” object while the flap is open, it registers a jam.
- Rectification: Upon detection, the servo motors execute a specialized ”shake” sequence—rapidly oscillating the flaps between limits.
- Advantage: This creates a high-displacement physical shock that breaks the arch of the jam at a low frequency that does not interfere with the IMU.

### 4.2 Mathematical Design and Dynamics

This section validates the physical design of the hopper, the sorting V-file, and the dispensing mechanisms using foundational Newtonian mechanics. The calculations evaluate the hopper’s flow characteristics, prove how the V-file passively controls speed, and verify that the chosen servo motor can handle the physical loads and timing required for single-ball dispensing.

### 4.2.1 Hopper Flow Kinematics and Dead Zone Analysis

The hopper must be designed so that gravity naturally overcomes the static friction between the seedballs and the aluminium walls. Due to spatial constraints within the drone fuselage, the hopper utilizes a highly asymmetric design with wall angles of 80◦ and 25◦
from the horizontal.

Gravity vs. Friction For a seedball of mass m resting on a wall angled at θ, gravity acts downwards. We resolve this gravitational force into two components relative to the surface:

- The driving force pulling the ball down the slope: Fdown = mg sin(θ)
- The normal force pressing the ball into the wall: N = mg cos(θ)

The friction force (Ff ) resisting the flow depends on the coefficient of friction (µ) between the rough clay seedball and the aluminium wall:
Ff = µ · N = µmg cos(θ)

The Flow Condition For continuous flow, the downward driving force must strictly exceed the resisting friction force:
mg sin(θ) > µmg cos(θ)

Dividing both sides by mg cos(θ) yields the critical threshold for gravity-driven flow:

tan(θ) > µ

Design Verification Rough, soil-based seedballs have a high coefficient of friction, conservatively estimated at µ ≈ 0.80. Let us evaluate both walls:

- Steep Wall (80◦

): tan(80◦
) ≈ 5.67. Since 5.67 ≫ 0.80, gravity completely dominates. Flow along this wall is guaranteed with a massive safety factor.
- Shallow Wall (25◦

): tan(25◦
) ≈ 0.466. Since 0.466 < 0.80, the frictional resistance is significantly stronger than the gravitational pull.

Conclusion: The mathematics confirm that while the 80◦ wall will clear rapidly, the 25◦ wall creates a static

”dead zone.” This analysis justifies the absolute necessity of the active jam-rectification system. The low-frequency servo ”shake” mechanism is explicitly required to break the static friction limit (0.466 < 0.80) on this shallow plane, transferring the remaining payload into the active flow region.

### 4.2.2 V-File Dynamics: Passive Braking

The primary purpose of the V-profile channel (V-file) is to align the seedballs and decelerate them before they reach the servo gate. This braking effect is achieved passively by manipulating the normal force geometry.

Normal Force Amplification On a standard flat ramp inclined at an angle ψ, the normal force (Nf lat) that dictates friction is simply:
Nf lat = mg cos(ψ)

However, in a V-channel with a dihedral angle of β, the sphere contacts two angled walls. The total effective normal force (Nef f ) pushing against the walls increases due to a wedge effect:

Nef f =

mg cos(ψ)
sin(β/2)

The Braking Calculation Our design utilizes a dihedral angle of β = 90◦ , chosen for manufacturing simplicity and optimal centering force. Evaluating this:

sin(90◦

/2) = sin(45◦
) ≈ 0.707

Nef f =

Nf lat
0.707

≈ 1.414 × Nf lat

Conclusion: The 90◦ V-groove geometry dramatically increases the normal force by approximately 41% com-

pared to a flat surface. Because friction is directly proportional to normal force, this geometry acts as a highly effective passive brake. The increased wedge friction reliably reduces the seedball’s rolling acceleration to approximately 2.8 m/s² without requiring additional moving components.

### 4.2.3 Servo Actuator Dynamics

The dispensing mechanism relies on a micro-servo acting as an escapement gate. We must mathematically verify that the motor possesses sufficient static torque to hold the payload, and appropriate kinematic timing to ensure singulation (dropping exactly one ball).

A. Static Torque Analysis
- Given Variables:

– Mass per seedball (m) = 0.025 kg

– Maximum queue capacity (n) = 12 balls

– Incline angle of the V-file (ψ) = 30◦

– Servo arm length (L) = 0.02 m

The total gravitational force pulling the column of balls down the 30◦ slope is:

Fslope = (n · m · g) sin(ψ)

Fslope = (12 · 0.025 · 9.81) · sin(30◦ ) ≈ 1.47 N

The torque (τ ) exerted on the servo arm is:

τ = Fslope × L

τ = 1.47 N × 0.02 m ≈ 0.0294 Nm

Converting Newton-meters to the industry standard of kilogram-centimeters (kg-cm), the load is approximately 0.30 kg-cm.
Safety Factor (SF): The selected MG90S servo motor has a rated stall torque of 1.8 kg-cm.

SF =

1.8
0.30

= 6.0

The actuator possesses a 6× safety margin, ensuring reliable operation without stalling under full load.

B. Kinematic Separation (Singulation Analysis) To prove single-ball dispensing, we compare the exit times of the first and second seedballs when the gate opens from a resting state (u = 0).
Using the kinematic equation for displacement (d =

1/2 at²
), we solve for time:

t =

r
2d
a

Assuming the 90◦ V-file deceleration yields a = 2.8 m/s² and the seedball diameter is D = 0.025 m:

- Time for Ball 1 to exit (t1): Ball 1 travels distance D.

t1 =

r
2(0.025)
2.8

≈ 0.133 s = 133 ms

- Time for Ball 2 to exit (t2): Ball 2 starts one diameter behind, traveling distance 2D (0.050 m).

t2 =

r
2(0.050)
2.8

≈ 0.189 s = 189 ms

The Actuation Window: A standard micro-servo executing a rapid release cycle takes approximately 150 ms to open and close.
Comparing the temporal constraints:

133 ms (t1) < 150 ms (Servo Cycle) < 189 ms (t2)

### 4.3 Hopper Geometry

The hopper sub-system functions as the primary payload reservoir and the first stage of the feed mechanism. Its geometry is the critical determinant in achieving a ”Mass Flow” regime—where the entire payload is in motion during discharge—preventing ”Funnel Flow” (stagnation and ratholing). The design adopts a custom asymmetric pyramidal frustum configuration, optimized for the specific rheology of hand-rolled seedballs.

### 4.3.1 Geometric Configuration and Wall Inclination

To maximize volumetric efficiency within the UAV fuselage while strictly adhering to flow dynamics constraints, the hopper utilizes a four-wall architecture with differential inclination angles.

1. Asymmetric Pyramidal Frustum: Unlike conventional symmetric hoppers, the geometric centre of the inlet does not align with the outlet. This asymmetry allows the hopper to interface directly with the edge-mounted slot outlet, reducing the overall vertical profile of the dispenser.

2. Inclination Angles: The wall angles are derived from the Jenike Shear Cell theory for granular flow. To ensure gravity overcomes the internal friction of the seedballs (which have a high coefficient of friction due to soil/clay composition), the walls are set at steep angles:
- Longitudinal Walls: The two primary walls running parallel to the slot outlet are inclined at from the horizontal. This steep angle is critical as it exceeds the seedballs’ Angle of Repose (typically 35°–45° for rough spheres) by a significant safety factor (approx. 1.5x). This ensures that material near the slot walls cannot stagnate or form ”ledges.”

## 5 Material Selection

The hopper assembly is dynamically mounted to a UAV frame, functioning as an active payload deployment system. The engineering constraints mandate a strict balance between mass reduction and structural integrity to ensure both flight stability and operational reliability over rugged terrain.

### 5.1 Structural and Kinematic Requirements

Because the assembly must safely store and deploy variable organic payloads while subjected to flight kinematics, the selected material must satisfy two absolute prerequisites:

- High Structural Rigidity: To prevent dimensional warping under load, ensuring the internal feed mechanisms do not bind.
- Low Material Density: To preserve the drone’s thrust-to-weight ratio, maximizing flight time and payload capacity.

### 5.2 Material Evaluation and Rejection

Phase 1: Additive Manufacturing Polymers

Given the complex, asymmetric geometry of the hopper (as detailed in Section 3.2), 3D printing was initially evaluated as a primary fabrication method.
Failure (Mechanical Limitations): While polymers (such as PLA, ABS, or PETG) offer significant mass reduction, they inherently lack the ultimate tensile strength and stiffness required for a structural reservoir. Furthermore, standard FDM/SLA polymers possess poor vibration attenuation characteristics. The harmonic vibrations generated by the UAV rotors would propagate through the polymer chassis, potentially disrupting the singulation of the seedballs in the V-File.

Phase 2: High-Strength Ferrous Metals

To achieve the requisite dimensional stability, the design shifted to metallic alloys. Steel was evaluated as the industry standard for high-strength hoppers.
Failure (Mass Penalty): In spite of its superior structural strength and rigidity, steel is prohibitively dense. Incorporating a steel hopper would incur an unacceptable weight penalty, severely degrading the UAV’s manoeuvrability, battery life, and overall seedball payload capacity.

### 5.3 Final Selection: Aluminium Alloy (4xx.x Series)

Aluminium was selected as the definitive material for the core structural components, perfectly bridging the gap between the two primary mechanical requirements. The 4xx.x series was specifically chosen for its superior fluidity and minimal solidification shrinkage, making it the industry standard for complex casting.

- Volumetric Mass Optimization: Aluminium offers an optimal strength-to-weight ratio. With a low material density, the total calculated mass of the hopper assembly — inclusive of the 15 cm upper storage unit and the intermediate transition section — is restricted to an optimized 2.85 kg.
- Environmental Resilience: Aluminium provides excellent natural corrosion resistance due to its passivation layer. This is critical given the assembly’s continuous exposure to soil, moisture, clay, and abrasive dust inherent to hand-rolled seedballs.
- Machinability: The alloy demonstrates high machinability and weldability, allowing for seamless integration with secondary sheet metal components.

### 5.4 Fabrication Methodology

The fabrication strategy was divided into two distinct processes based on the geometric complexity, cross-sectional variance, and structural requirements of the individual sub-components.

### 5.4.1 Primary Assembly Fabrication (Die Casting)

The core hopper architecture, upper storage unit, servo motor mounts, and intermediate transition parts feature complex curved surfaces, specific draft angles, and varying wall thicknesses. These geometries render standard subtractive machining (CNC) highly inefficient.
Process Selection: Cold Chamber Die Casting was identified as the most appropriate manufacturing process. Die casting outperforms sand or investment casting by producing a superior surface finish (minimizing internal wall friction) and causing fewer thermal distortions.
The Cold Chamber Process: Because aluminium alloys require high processing temperatures that would degrade a standard hot-chamber pumping system, the cold chamber variant is utilized.
Execution: The 4xx.x aluminium alloy is melted in an external furnace. The molten metal is then ladled into an injection chamber. A hydraulic piston forces the liquid metal into the two halves of a hardened steel mould cavity under extremely high pressure, ensuring complete filling of the asymmetric hopper walls before solidification.

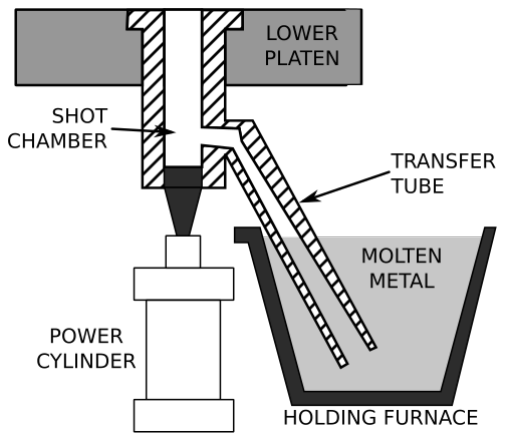
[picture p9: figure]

Figure 5: Cold Die-casting

### 5.4.2 Secondary Component Fabrication (Sheet Metal Forming)

The V-File component (the singulation channel) features a strictly planar, less geometrically complex architecture. Therefore, casting would be an unnecessary expense.
Process Selection: Bending and Welding.
- Forming: The V-File is manufactured via standard sheet metal bending operations, utilizing aluminium stock with a uniform thickness of 2 mm.
- Integration: Post-forming, the V-File channel is permanently affixed to the intermediate die-cast section of the hopper through structural welding, ensuring a rigid and seamless transition for the seedballs.

### 5.5 Dimensional Tolerances

To ensure precise mechanical assembly, reliable kinematic function of the servo escapement, and repeatable mass flow, strict dimensional controls must be maintained during fabrication.

### 5.5.1 Industrial Die-Casting Guidelines

Standard industrial die-casting tolerances have been mathematically established to account for thermal expansion and tool wear. A commonly accepted industrial guideline for aluminium die casting has been applied:

- Base Tolerance: For the first inch of linear length.
- Incremental Tolerance: For every additional inch thereafter.

T = 0.25 + 0.025(L − 1)

Where T is in mm and L is in inches.

## 6 Electronics Architecture

The electronics architecture relies on a dual-rail buck converter that isolates the main 12V battery into separate power lines for the sensitive low-voltage logic board and the high-current servos. At its core, an ESP32 microcontroller processes physical payload data from a five-node infrared sensor array. Based on this data, the ESP32 actuates the drop gates via PWM signals while simultaneously broadcasting live MAVLink telemetry over a hardwired UART connection to the flight controller.

### 6.1 Power Subsystem

A dual buck converter design splits the main 12V battery to isolate high-current servo loads from sensitive logic circuits.

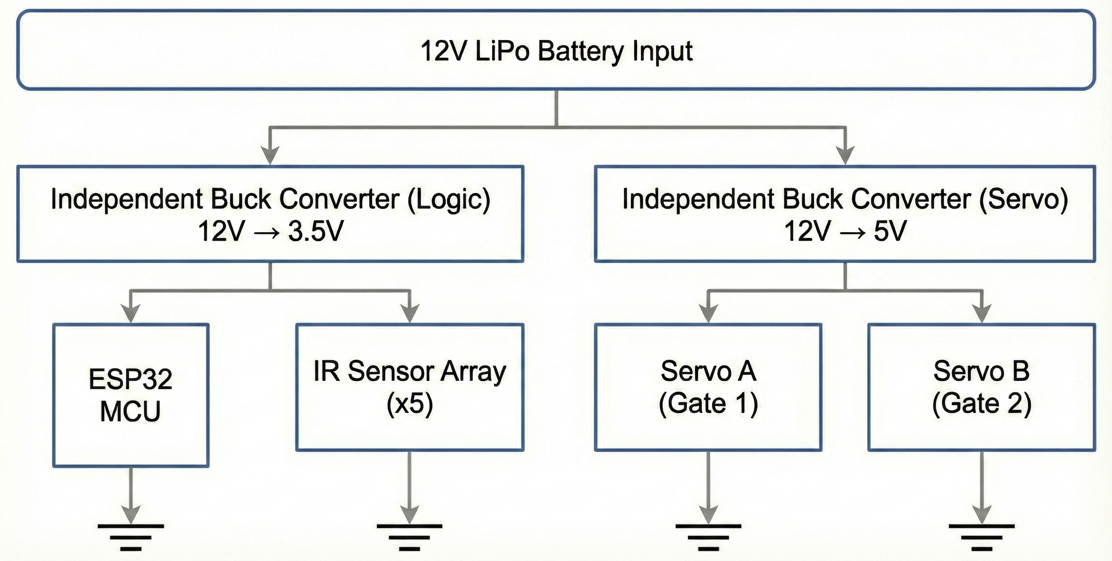
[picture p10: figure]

Figure 6: Power Subsystem Architecture and Dual-Rail Regulation

### 6.1.1 Architecture

The power architecture utilizes a dual buck converter design to isolate high-current mechanical loads from sensitive logic circuits. A dedicated converter steps down the main 12V battery voltage to a 6V rail, providing optimal torque for the dual servo motors. This prevents severe voltage drops when the motors stall or sweep. A secondary converter regulates voltage for the ESP32 logic controller and the 3.3V IR sensor array. All power and signal subsystems are tied to a unified ground plane (GND) to eliminate ground loops and maintain signal integrity across the UART and PWM communication lines.

### 6.1.2 Power Consumption by Subsystem

To calculate the total system load on the drone’s 12V LiPo battery, the consumption is divided between the Logic Rail (3.5V) and the Actuator Rail (5V).

- Logic Rail (Continuous Load): The ESP32 draws approximately 160 mA to 240 mA while operating with active Wi-Fi and hardware UART routing. The five active IR transmitter/receiver pairs draw approximately 20 mA each, totaling 100 mA. The total logic load is ∼340 mA at 3.5V (∼1.19 Watts).
- Actuator Rail (Transient Load): Only one servo actuates during a standard drop command. In an idle state, both servos hold position at 0

◦
, drawing a total of 40 mA. During an active sweep, a single servo draws approximately 500 mA to 800 mA under physical load. In a stall condition caused by a physical jam, the servo will pull a peak current reaching up to 2.0 A to 2.5 A until the timeout logic closes the gate.

### 6.1.3 Total System Power State

Assuming the buck converters operate at a standard 80% efficiency, the actual current drawn from the main 12V flight battery is categorized into three flight states:

- State 1 (Standby/Idle): The payload draws ∼145 mA from the 12V battery.
- State 2 (Active Deployment): The payload draws a transient spike of ∼550 mA from the 12V battery for the duration of the 1000ms timer.
- State 3 (Critical Jam): The payload draws a maximum peak of ∼1.4 Amps from the 12V battery.

### 6.1.4 Power Architecture Conclusion

Because the maximum stall current of a jammed servo can pull up to 1.4A from the main battery, isolating the ESP32 behind its own independent buck converter is strictly necessary. If the servos and MCU shared a single 5V regulator, the 12.5W stall spike would cause a severe voltage droop, instantly resetting the ESP32 and severing the MAVLink heartbeat to the flight controller.

### 6.2 Control System

The control system utilizes an ESP32 running a non-blocking state machine to execute drop commands and broadcast MAVLink telemetry without interrupting the main processing loop. It continuously monitors the IR sensor array to actuate the servo gates and will autonomously trigger a high-frequency agitation routine to clear any detected mechanical jams.

### 6.2.1 Non-Blocking State Machine Algorithm

The central processing unit is an ESP32, selected for its robust real-time I/O capabilities. To maintain a high-frequency MAVLink heartbeat and instantly process incoming serial commands, the core dropping algorithm strictly avoids standard blocking functions. The firmware utilizes a real-time hardware timer state machine, which allows the processor to simultaneously sweep the physical servos, parse high-speed UART packets, and push MAVLink telemetry to the flight controller without missing a single clock cycle. The drop execution function is dynamic and intercepts comma-separated serial commands to alter the gate’s sweep angle and duration on the fly based on the drone’s velocity and altitude.

### 6.2.2 Fault-Tolerant Failover Logic

The payload is designed with an Active/Standby redundancy algorithm to autonomously survive mechanical failures during flight.

- Drop Verification: Upon opening the active drop gate, the algorithm actively polls the exit sensor. A brief LOW signal acts as a digital turnstile, confirming a successful seed deployment.
- Jam Detection & Isolation: If the gate actuation timer expires and no drop is confirmed, the algorithm cross-references the active V-file sensors; if they read LOW, a mechanical bridge or jam is mathematically confirmed.
- Autonomous Redundancy: Upon jam confirmation, the software immediately locks the primary file’s servo to 0
- and permanently re-routes all subsequent drop commands to the secondary backup file.

### 6.2.3 Automated MAVLink Feedback Loop

The mechanical state of the control system is directly tied to the drone’s primary telemetry stream via a dedicated hardware serial line at 57600 baud. A heartbeat is generated at 1Hz, verifying payload power and logic loop integrity to the Ground Control Station. When the failover algorithm shifts from File A to File B, the system injects a critical status text into the data stream, translating mechanical fault logic into an immediate, human-readable alert on the pilot’s HUD.

### 6.2.4 Conclusion

By coupling a hardware-timed, asynchronous execution loop with autonomous sensor-driven redundancy, the payload control system guarantees zero-latency command ingestion. This ensures mechanical blockages are instantly bypassed without interrupting the critical telemetry stream to the primary flight controller.

### 6.3 Communication Protocol

The system uses a direct wired connection to talk to the drone’s main flight controller using standard MAVLink messages. This allows the payload to send live health updates and jam warnings to the pilot through the drone’s existing radio, saving the weight of extra equipment.

### 6.3.1 Integrated Telemetry Architecture

- To transition the dispenser from an isolated mechanism into an integrated aerospace payload, the system implements the MAVLink v2.0 protocol.
- This protocol allows the payload to communicate directly with the drone’s primary Flight Controller, such as a Pixhawk or Cube.

### 6.3.2 Wired UART Integration

- For industrial reliability and long-range flight safety, the final flight configuration utilizes a hardwired serial connection.
- Physical Link: The ESP32 utilizes a dedicated hardware serial port operating at a standardized 57600 baud rate.
- Data Routing: The ESP32’s TX and RX lines are wired directly into an available TELEM port on the drone’s Flight Controller.
- This physical link establishes a common ground to prevent voltage offset errors.

### 6.3.3 MAVLink Packet Multiplexing

- The ESP32 assumes the identity of a primary flight node (SYSTEM ID = 1, COMPONENT ID = 1).
- Persistent Heartbeat: The system constructs and broadcasts a MAVLINK MSG ID HEARTBEAT packet every 1000ms to maintain network presence with the flight controller.

- Priority Interrupt Alerting: When a mechanical jam is confirmed, the logic loop triggers a priority interrupt. The system constructs a STATUSTEXT packet (ID #253) encoded with the MAV SEVERITY CRITICAL flag and a dynamic diagnostic string (e.g., “WARNING: FILE A JAMMED”).
- Ground Station Delivery: The Flight Controller receives this UART packet, multiplexes it with the primary flight telemetry (GPS, IMU, Attitude), and transmits the combined data stream over the drone’s long-range radio to the Ground Control Station (GCS).

### 6.3.4 Protocol Validation (SITL Methodology)

- Prior to physical hardware wiring, the payload’s logic and MAVLink packet construction were rigorously verified using a Software-In-The-Loop (SITL) environment.
- A simulated ArduPilot flight stack and a MAVProxy network router were deployed for this validation.
- The ESP32 payload utilized its Wi-Fi capabilities to inject simulated hardware faults into the localized network via UDP packets.
- MAVProxy successfully intercepted the payload’s asynchronous STATUSTEXT packets.
- The reception of the MAV SEVERITY CRITICAL flag successfully bypassed standard telemetry logs and immediately triggered a high-priority visual warning banner within the QGroundControl interface, verifying the payload’s network behavior and logic integrity.

### 6.4 Logic Flow

The system operates on a continuous loop to execute drop commands and instantly verify successful deployment via the exit sensors. If a blockage occurs, the software autonomously oscillates the gate to clear the jam before seamlessly rerouting to the backup mechanism.

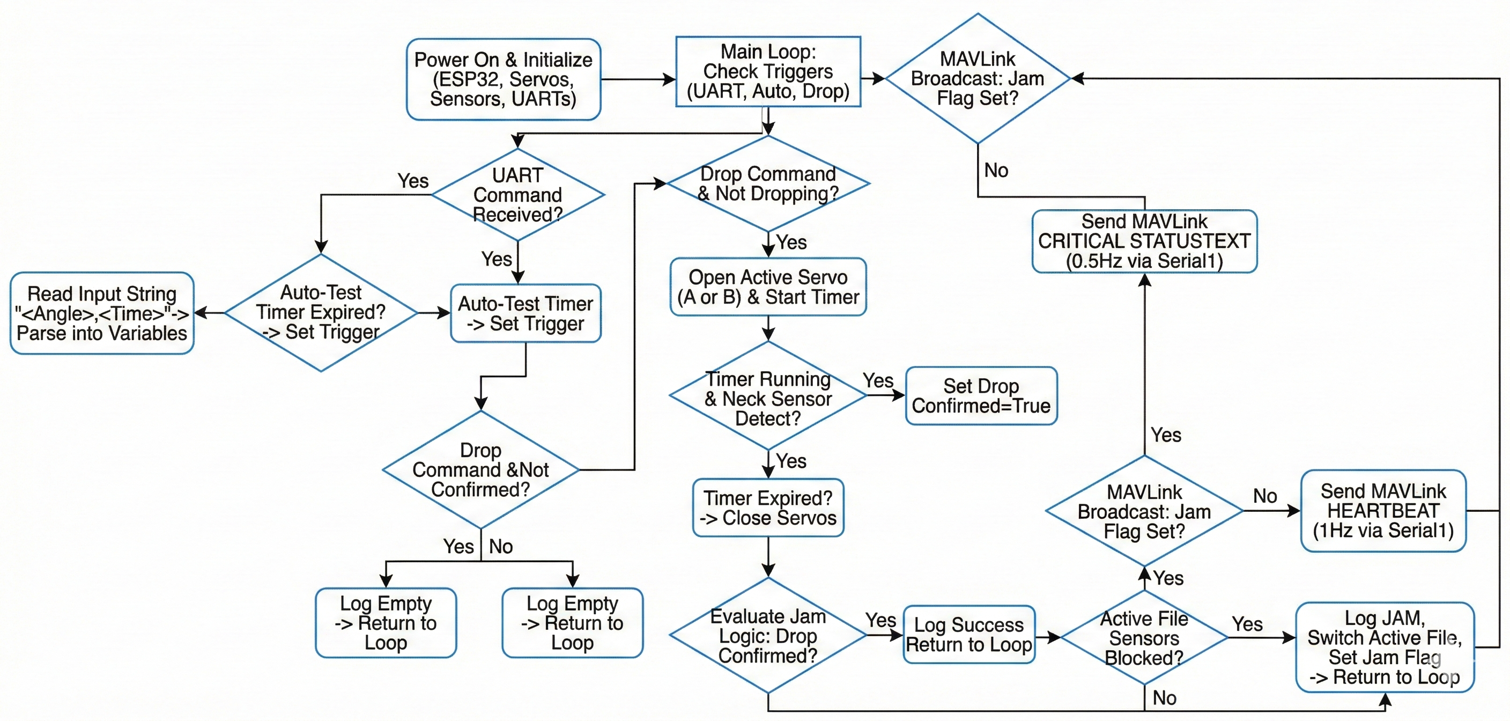
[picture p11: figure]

Figure 7: Logic Flow Chart

### 6.4.1 Non-Blocking State Machine Execution

The payload operates on an asynchronous state machine designed to execute commands, verify physical actions, and gracefully recover from mechanical failures without requiring pilot intervention.
To maintain a high-frequency MAVLink heartbeat and instantly process incoming serial commands, the core dropping algorithm strictly avoids standard blocking functions (like delay()). The firmware utilizes a real-time hardware timer (millis()) state machine. This concurrent execution strategy allows the processor to simultaneously sweep the physical servos, parse high-speed UART packets from the companion computer, and push MAVLink telemetry to the flight controller without missing a single clock cycle.

### 6.4.2 Drop Command & Multi-Layered Verification

The drop execution function is fully dynamic. The system receives primary target angles and timing durations via a dedicated command UART line. It intercepts comma-separated serial commands (<TargetAngle>,<OpenTimeMs>), allowing the onboard companion computer to alter the gate’s sweep angle and duration on the fly based on the drone’s velocity and altitude.
Upon receiving a command, the system initiates a timed drop sequence, but drop success is never assumed. The algorithm actively polls the IR NECK exit sensor. A brief LOW signal acts as a digital turnstile, explicitly confirming a successful seed deployment within the logic loop.

### 6.4.3 Dynamic Jam Resolution & Redundancy

The payload is designed with an Active/Standby redundancy algorithm to autonomously survive mechanical failures during flight. If the sequence window expires without a confirmed drop at the exit chute, the system queries the upper diagnostic sensors.

- Empty File: If the upper diagnostic sensors read clear, the system logs the active file as empty and seamlessly transfers active control to the redundant file for the subsequent drop command.
- Jam Condition: If the active V-file sensors read LOW (indicating material is present but not falling), a mechanical bridge or jam is mathematically confirmed.
- Autonomous Failover: Upon jam confirmation, the software immediately disables the active file by locking its servo to 0. It permanently re-routes all subsequent drop commands to the secondary backup file (activeFile = 2) and initializes a critical telemetry alert sequence.

### 6.4.4 Automated MAVLink Feedback Loop

The mechanical state of the control system is directly tied to the drone’s primary telemetry stream via a dedicated hardware serial line (Serial1 @ 57600 baud).

- System Health: A MAV TYPE QUADROTOR heartbeat is generated at 1Hz, verifying payload power and
logic loop integrity to the Ground Control Station (GCS).
- Fault Broadcasting: When the failover algorithm shifts from File A to File B, the system injects a MAV SEVERITY CRITICAL status text into the data stream. This translates the mechanical fault logic into an immediate, human-readable
alert (e.g., “WARNING: FILE A JAMMED”) on the pilot’s HUD.

### 6.5 Jamming Detection & Active Rectification

### 6.5.1 Autonomous Fault-Tolerance Overview

- The payload operates on an asynchronous state machine designed to execute commands, verify physical actions, and gracefully recover from mechanical failures without requiring pilot intervention.

### 6.5.2 Multi-Layered Drop Verification

- During a drop sequence, success is never assumed.
- Upon opening the active drop gate, the algorithm actively polls the final exit sensor.
- A brief LOW signal acts as a digital turnstile, confirming a successful seed deployment within the logic loop.

### 6.5.3 Jam Detection and High-Frequency Agitation

- If the gate actuation timer expires and no drop is confirmed, the algorithm cross-references the active V-file sensors.
- Empty File Identification: If the upper diagnostic sensors read clear, the system logs the active file as empty and seamlessly transfers active control to the redundant file for the subsequent drop command.
- Jam Confirmation (Neck Blockage): If the diagnostic sensors read blocked (LOW, indicating material is present but not falling), a mechanical bridge or jam is mathematically confirmed.
- Active Jam Rectification: Upon detecting a blockage at the neck, the system intercepts the failover sequence to attempt an active physical recovery.
- The blocked servo motor is driven to oscillate at a small amplitude and high frequency.
- This rapid mechanical agitation introduces kinetic energy into the V-file, designed to shatter the structural arch of the jammed seed balls and force the material through the exit chute.

### 6.5.4 Autonomous Failover and Telemetry Alerting

- Redundancy Rerouting: If the high-frequency oscillation routine fails to clear the exit neck, the software immediately disables the active file by locking its primary servo to 0.
- Active control is then permanently re-routed to the secondary backup file for all subsequent drop commands.
- Critical Alert Generation: The logic loop triggers a priority interrupt and constructs a STATUSTEXT packet encoded with the MAV SEVERITY CRITICAL flag.
- Pilot Notification: This translates the mechanical fault logic into an immediate, human-readable alert (e.g., “WARNING: FILE A JAMMED”) on the pilot’s HUD.

## 7 Software Framework for Proof-of-Concept Simulation

This section details the custom software framework engineered to simulate the granular dynamics of seedballs flowing through the payload dispenser. By establishing a high-fidelity digital twin of the hopper, the system provides a robust proof-of-concept (PoC) to evaluate jam resistance and mechanical efficiency prior to physical fabrication.

### 7.1 Automated Simulation Orchestration

To rigorously validate the mechanical design of the dispensing hopper prior to physical manufacturing, a customized software framework was developed to orchestrate a high-fidelity physics simulation. This framework serves as a vital Proof-of-Concept (PoC) tool, specifically designed to analyze granular flow kinematics and predictively identify potential jamming or bridging bottlenecks. By simulating these physical interactions in a digital environment, the engineering team can rapidly iterate on hopper angles and throat diameters without the cost and time overhead of physical prototyping.

### 7.1.1 Dynamic Structural Instantiation

The initialization sequence programmatically constructs the digital workspace at runtime rather than relying on static, pre-compiled environments. The framework automatically parses the foundational CAD and kinematic models (Xacro/URDF) of the dispenser.
It translates these structural parameters into a standardized format and injects the exact mechanical geometry into an empty, gravity-enabled physics solver. This process accurately maps all internal physical boundaries, surface angles, and the critical bottleneck throat. By establishing these absolute physical boundaries for subsequent flow testing, the software ensures the simulation perfectly matches the intended real-world hardware down to the millimeter.

### 7.2 Procedural Payload Synthesis

To accurately test the mechanism’s resistance to jamming, the software must replicate the unpredictable, heterogeneous nature of real-world seedballs. Real granular materials do not behave like uniform liquids or single rigid bodies. Rather than using uniform, pre-modeled spheres—which would yield falsely optimistic flow rates—the framework utilizes a procedural generation script that acts as an automated chaotic test-case synthesizer.

### 7.2.1 Algorithmic Object Construction

The script mathematically designs a batch of 75 distinct seedballs during the active execution loop. For every individual entity, the software generates a unique physical profile in memory.
This profile defines the precise geometric boundaries, visual characteristics, and complex collision surface parameters of the object. Crucially, the script assigns high-friction and high-stiffness coefficients to the outer collision mesh of each sphere, accurately mimicking the rough, baked-clay exterior of an actual seedball.
Once the mathematical profile is compiled into a valid simulation description format, the software issues a subsystem command to inject the new entity directly into the active physics environment for immediate collision processing.

### 7.2.2 Controlled Spatial Distribution

To prevent the physics engine from failing due to instantaneous mesh overlap—which causes violent, infinite-force expulsions in rigid-body solvers—the software employs a three-dimensional spatial offsetting algorithm.
The script calculates precise Cartesian coordinates to organize the incoming payload into a structured grid pattern suspended above the hopper.

### 7.3 Dynamic Physics Assignment and Flow Diagnostics

The core intelligence of the testing script lies in its mathematical distribution algorithms. These algorithms ensure the simulation stresses the hopper design exactly as a diverse biological payload would in a real-world reforestation mission.

### 7.3.1 Variance Modeling for Jam Prediction

Every generated entity undergoes a randomized property assignment based on predefined biological variances ranging from 15 mm to 35 mm. The software utilizes uniform randomization algorithms to dictate the specific diameter d of each object:

d ∼ U(15 mm, 35 mm)

Once the randomized geometric size is established, the script automatically derives the exact physical properties required by the rigid-body solver.

Volume and Mass The volume V of each spherical seedball is calculated as:

V =

4
3

πr³

The mass m is then derived using a baseline biological density:

ρ = 1500 kg/m³

m = ρV

Moment of Inertia The rotational inertia matrix I for a solid sphere is:

I =

2
5

mr²

This dictates how uniquely the object tumbles and resists angular momentum changes as it falls.
By embedding these unique physics properties into each object, the software creates a highly realistic, chaotic flow scenario. Differently weighted and sized objects interact, interlock, and collide at varying velocities, which is the primary cause of granular bridging, arching, and mechanical jamming at the hopper’s throat.

### 7.3.2 Visual Analytics Mapping

To assist the engineering team in analyzing sorting behavior and identifying exact jam locations, the software includes a visual mapping algorithm. It mathematically normalizes the randomized size data and translates it into an RGB color gradient:

- Small Entities: Assigned one end of the color spectrum (e.g., green).
- Large Entities: Assigned the contrasting end (e.g., red).
- Median Entities: Assigned transitional gradient colors (e.g., yellow/orange).

This creates a clear, immediate visual indicator of mass distribution throughout the payload. By observing the color gradient during the simulation, operators can instantly verify whether the hopper successfully funnels all sizes evenly. More importantly, it visually demonstrates whether large masses (red spheres) preferentially lock together at the dispensing bottleneck to cause a jam, or if the system suffers from granular convection—where smaller seedballs (green spheres) improperly filter to the bottom while larger ones float to the top.

## 8 Analysis

### 8.1 FEM & FEA

Finite Element method is a numerical technique used to find accurate solutions to boundary value problems for partial differential equations. Basically, a complex geometry is transformed into a mesh composed of several small shapes called elements (most commonly tetrahedrons or triangles). These elements are connected at specific points called nodes. FEM converts the PDEs (which are extremely difficult to solve, given any geometry) into a system of algebraic equations that a computer can solve with relative ease.
Finite Element Analysis is the practical application of FEM to simulate how a design reacts to real-world forces. In the context of our design, FEA is used to predict how the weight of material (static load) affects the structural integrity. FEA predicts if the structure will bend or break under its own static load. It allows for iterative design meaning you can thin out a part to save weight without ever touching a physical prototype.

### 8.1.1 Equivalent Stress Analysis:

Equivalent stress analysis essentially decomposes a 3D stress state into a single scalar value and maximum principal stress finds the maximum normal stress acting on a plane where the shear stress is zero. The values show that there is no pile-up of forces under the weight of the structure itself, ensuring that the structure is stable and is not prone to suffering failure due to stress at any point on the design. The values obtained for strain also show that there is no significant deviation from the structure’s original shape and thus we can say that the strain on the design is also very well controlled.

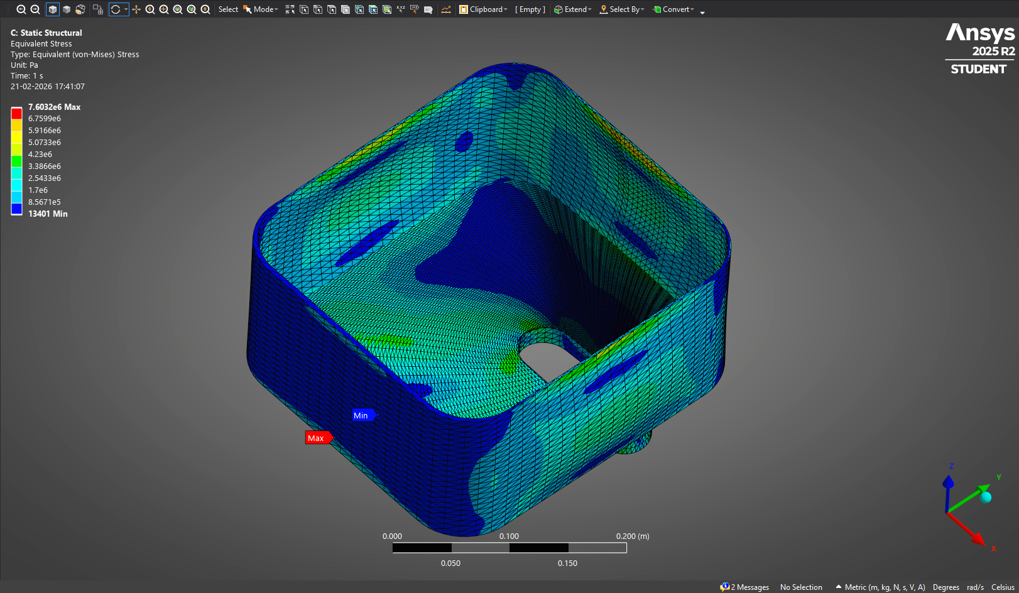
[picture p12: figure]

(a) (b)

Figure 8: Equivalent Stress-Strain

### 8.1.2 Maximum Principal Stress-Strain

For maximum principal stress, the values and the contour map also indicate that even under the worst-case scenario load, our design is not at risk of failure. Also to note, is that the maxima of the values calculated under FEA show that the region suffering the most stress is not where the seedballs will regularly interact or strike. For the maximum principal strain analysis, it should be noted that even under the most dire conditions, our design would hold up.

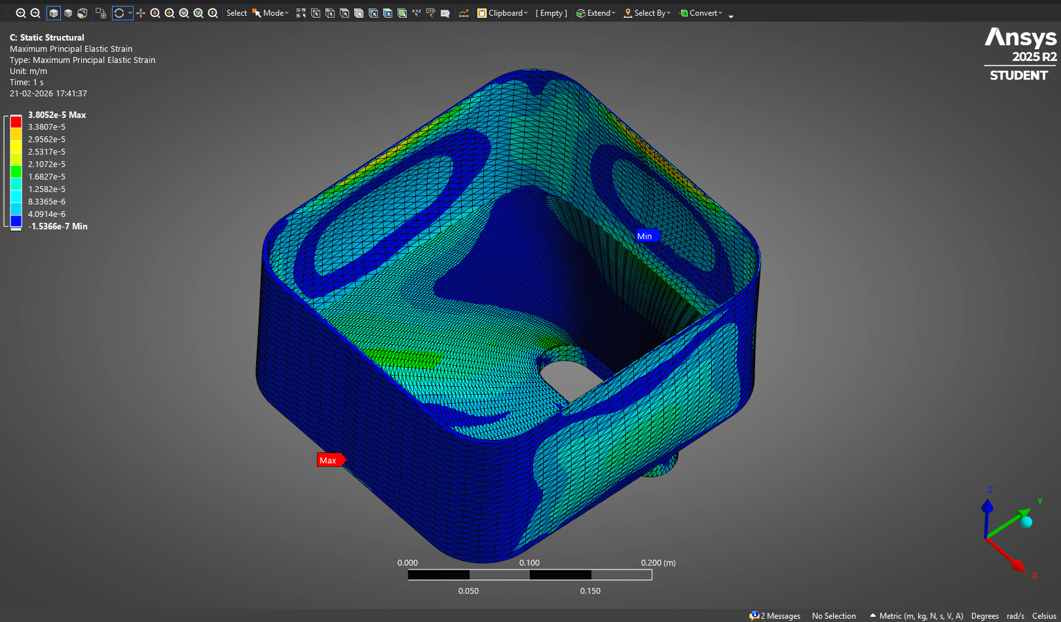
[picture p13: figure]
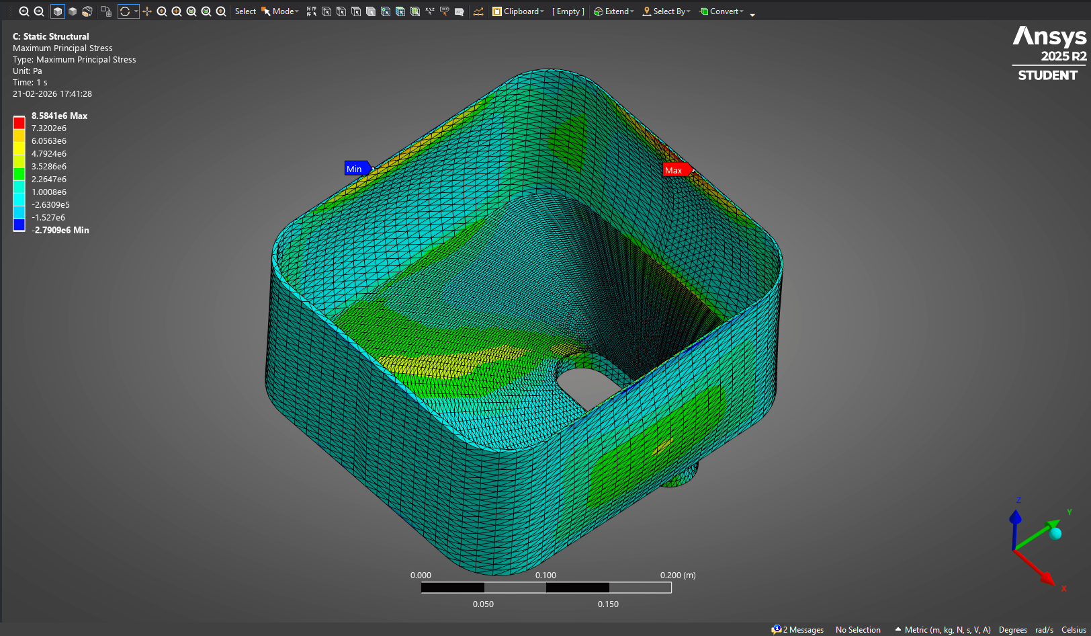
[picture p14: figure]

(a) (b)

Figure 9: Maximum Principal Stress-Strain

### 8.1.3 Volume Deformation:

Volume deformation refers to the change in physical space an object occupies when subjected to stress. Strain energy is the work done by external loads to deform a material within its elastic limit, which is recoverable upon unloading. The contours show that although the hopper suffers from deformation, it is not significant and the values clearly show that no failure could possibly occur.

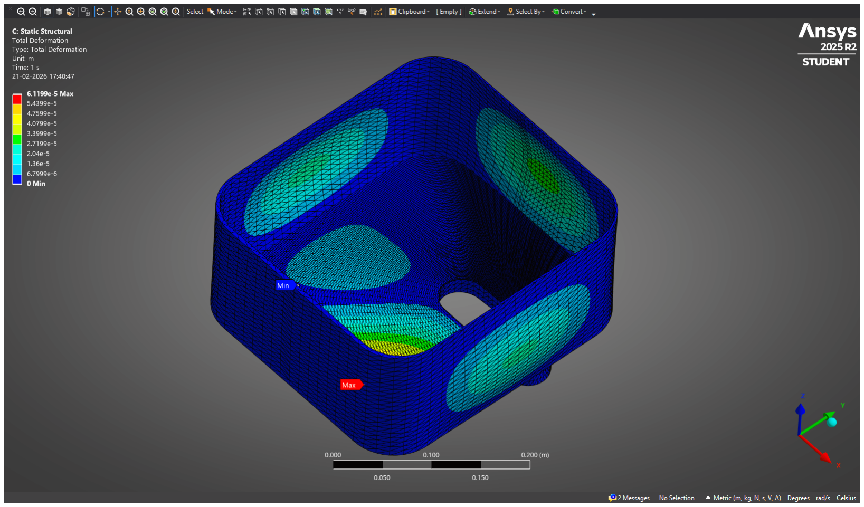
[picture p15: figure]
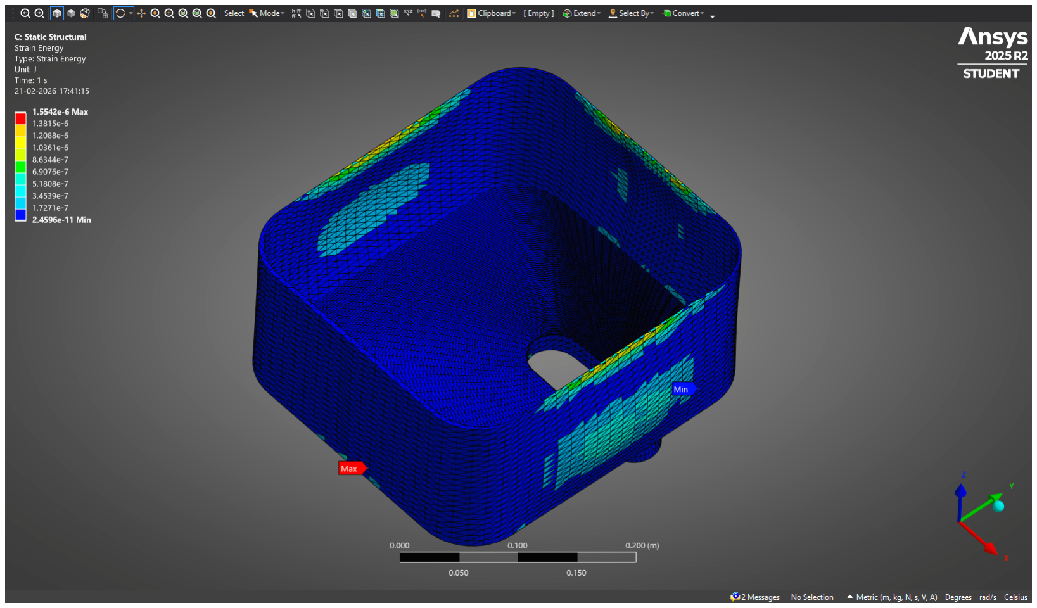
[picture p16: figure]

(a) Volume Deformation | (b) Strain Energy

Figure 10: Volume Deformation and Strain Energy

### 8.1.4 Strain Energy

Following our discussion deformation, the energy that is subsequently stored in the structure is shown as above. Even at its maxima, the values are not significant and show no risk of catastrophic failure.

### 8.2 Modal Analysis

Modal Analysis Explanation:
Modal analysis is a linear dynamic analysis used to determine the natural frequencies and mode shapes of a structure. It is critical for avoiding high-amplitude vibrations inside the structure and suffering subsequent chances of failure. Mode shapes predict the physical shape the structure will take at some frequency. This analysis allows for avoiding catastrophic failure where high amplitude vibrations cause any of the components used to break, buckle or shear.

Modal Analysis Simulation:
The key reason for modal analysis for any system is to avoid high amplitude vibrations occurring due to resonant frequencies that are produced by both internal and external factors. The given graph, contour map and values lay out a complete modal analysis of the design. Persistent vibrations of the given frequency are of course, avoided as far as possible (stemming from internal components such as the servos). However, even if momentary high amplitude vibrations occur, the design does not go through catastrophic failure and lies well within safe limits.

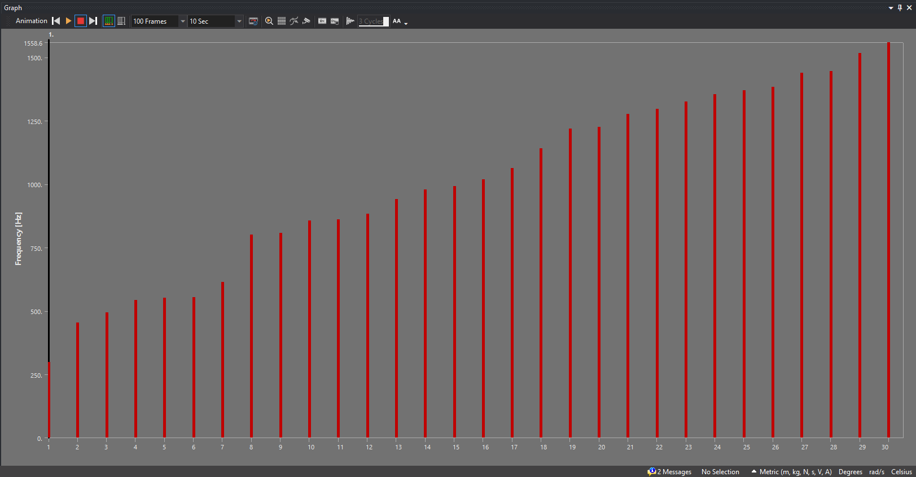
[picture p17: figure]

(a) Deformation due to Frequencies | (b) Frequency Analysis

Figure 11: Maximum Principal Stress-Strain

It is to be noted that the design is constructed with a safety factor of 2. The avoidance of failure is dependent on this, and it is not always mentioned explicitly.

## 9 Jamming

The reliability of the seedball dispensing mechanism is primarily dictated by its ability to maintain continuous flow despite the stochastic nature of the payload. As highlighted in the Problem Statement, the seedballs are non-uniform, irregular spheres ranging from 15 mm to 35 mm in diameter. This high variability, combined with the significant overburden pressure from the 15 kg payload, creates a high probability of flow obstruction. Jamming in this system is not a single phenomenon but rather a result of two distinct failure modes: static bridging at the hopper throat and dynamic mechanical interlocking within the metering mechanism.

### 9.1 Geometric Interlocking

Geometric interlocking, often referred to as ”arching” or ”bridging,” occurs at the transition zone where the bulk storage (hopper) narrows into the metering throat (the obround outlet).

1. Mechanism of Failure: Due to the irregular surface texture and shape of the seedballs. When multiple large seedballs (approx. 30-35 mm) arrive at the discharge outlet simultaneously, they can mechanically lock against each other and the hopper walls to form a stable structural arch.
2. The ”Keystone” Effect: Once these arch forms, it supports the entire weight of the seed column above it, effectively shielding the dispensing roller from the payload.

### 9.2 Sequential Jamming

Sequential jamming is a dynamic failure mode specific to the two parallel V-file dispensing channels. Unlike the static arching at the hopper throat, this jamming occurs along the length of the dispensing tracks.

1. Mechanism of Failure (Wedging): The V-profile is designed to align seeds in a single file. However, due to the high variance in seedball diameter (15–35 mm) and irregular sphericity, a large or oddly shaped seed can become stuck between the inclined walls of the V-channel. This interference fail creates a friction lock that exceeds the gravitational or vibrational force intended to move the seed.
2. The ”Stacking” Effect: Once a seed gets stuck in one of the two files, it acts as a physical barrier and once a seed is lodged in the channel, other seeds fall down due to gravity but cannot move past the lodged one. As they accumulate behind the lodged one, their kinetic energy is transferred to the stationary seed, thus increasing the compressive force on it. Eventually, a free-flowing stream of seeds transforms into a compacted and interlocked pile of seeds. In the end, the channel changes from a dynamic flow to a stationary, high-friction plug, thus increasing the chances of a jam.
3. Multi-Channel Dependency: Since the two V-files are supplied by a common hopper outlet, a blockage in one channel directly affects the overall flow behaviour of the system. When one path becomes obstructed, a greater portion of the incoming seedballs is redirected into the remaining open channel. This uneven feeding can increase particle crowding and interaction within the active path, raising the likelihood of further obstruction and cascading jamming events. Further the jamming effect of arching can also take place here also.

## 10 Mitigation

To keep the irregular seedballs flowing smoothly, the system needs two things: mechanical movement to break blockages and proper hopper design to prevent locking.

Active Vibration: - To prevent the ”Keystone Effect” explained in Section 8.1, the hopper outlet needs an active system to stop stable arches from forming.

Vibratory Excitation: - Using a low-frequency vibrator helps prevent both static bridging and repeated jamming inside the hopper and dispensing channel. High-frequency vibration can damage the structure or press the material tighter. Low-frequency vibration creates larger movements that break arches and friction locks without putting too much stress on the structure.

Installation Of V-file: - This design change divides the hopper outlet into two V-shaped channels. This improves flow control and reduces interference between seedballs. By splitting the payload into two smaller streams, the load and pressure in each channel decrease. This reduces the chance of seedballs locking together or forming arches. The V-shape also helps guide and align irregular seedballs, reducing random movement and wedging.

Jam Detection and Rectification Logic: - An IR (infrared) sensor-based mass flow detection system is used to monitor seed discharge continuously. The sensor is placed near the outlet to detect seedball movement. During normal operation, the sensor detects regular interruptions as seedballs pass through. If the flow rate drops a lot or no movement is detected for a fixed time, the system treats this as a jam or bridging problem at the hopper outlet.

Geometric and Material Optimization: - For a straight-line hopper, the following changes should be made to ensure smooth mass flow instead of funnel flow or bridging: To prevent the Keystone Effect, the hopper outlet width
(W) should be at least 2.5 to 3 times the diameter of the largest seedball (d-max).Since d-max is 35 mm, the outlet width should be at least 90–105 mm. The hopper walls should be inclined at an angle greater than 60° from the horizontal. This ensures that gravity is strong enough to overcome friction between the seedballs and the walls.

Redundant Locking and Leakage Prevention: - The dispensing system should stay closed by default if power is lost or a sensor fails. Spring-loaded flaps or high-friction rotary designs ensure that gravity alone cannot release the payload by accident.

Communication and Pilot Notification: - If a fail-safe condition is activated, a high-priority signal is sent to the flight controller or ground station. This allows the operator to stop the mission and safely recover the UAV before serious mechanical or electrical damage happens.

## 11 Risk Analysis And Failure Modes (FMEA)

### 11.1 Identification of Potential Failure Modes

Servo Motor Stall and Gear Failure: - The servo motor is used to open and close the flap to control the release of the payload. If the flap gets blocked or cannot move freely, the servo motor will still try to move to its set position. If there is no sensor or protection system to detect this problem, the motor will continue running under load. This can cause the motor to stall, damage the internal gears, or overheat. If the servo fails completely, the flap may suddenly open or stop working properly. This can lead to an uncontrolled release of the full 15 kg payload and may disturb the balance of the system.

Vibration-Induced Structural Fatigue: - During operation, continuous vibration occurs, especially when carrying a 15 kg payload. These vibrations create repeated stress on the frame and fasteners. Over time, this repeated stress can weaken the material .If the vibration frequency becomes close to the natural frequency of the structure, resonance can happen. In resonance, even small vibrations can cause large movements. This can increase stress on the frame, brackets, and joints. Over long use, screws can loosen, threaded connections can weaken, and important joints may lose tightness.

### 11.2 Risk Assessment

Assessment of Hopper Flow Risks: -

1. Likelihood: Flow blockage in a straight-line hopper is high because the design does not fully support smooth material flow.

Straight-line hoppers often cause funnel flow instead of full material flow. This creates dead zones near the walls. As the payload becomes less during operation, the internal pressure changes and reduces the force needed to keep the material moving.

2. Impact: Blockage or bridging inside the hopper is serious because it stops the system from working properly. When material cannot come out, the whole deployment process stops. This wastes battery power, uses extra flight time, and does not fully use the payload.

Assessment of Servo Actuation Risks: -

1. Likelihood: Medium–High. The wide size distribution of seedballs significantly increases the chance of obstruction during flap closure over extended missions.
2. Impact: Catastrophic. Permanent servo failure can cause uncontrolled flap opening, resulting in an instantaneous 15 kg payload dump that destabilizes the UAV and may lead to a crash.

Assessment of Vibrator and Structural Risks: -

1. Likelihood: Continuous vibration can slowly loosen screws and mounting parts over time. If the vibration frequency matches the natural frequency of the structure, resonance can increase vibration and stress on the frame and joints.
2. Impact: Loose structure may not cause immediate failure but can reduce performance and reliability. Loose brackets or mounts may cause small misalignment, leakage, or uneven movement.

Assessment of Payload Characteristics Risk: -

1. Likelihood: High. Irregular seedball geometry produces unpredictable interactions with the aluminium dispensing flaps.
2. Impact: Moderate. Inconsistent drop rates and uneven hinge loading accelerate mechanical wear, increasing maintenance frequency.

## 12 Future Scope

Although the current straight-line hopper with dual V-file mechanism works properly, there is still good scope to improve the system. In the future, the design can be made smarter, lighter, more reliable, and more automatic so that it can handle large-scale missions more efficiently. The following improvements can be considered:

1. Smart Flow Control System
Adaptive Drop Timing: In future versions, the system can automatically adjust the servo opening and closing time based on how fast the seeds are moving inside the V-file and how fast the drone is flying. This will help maintain equal spacing between seedballs on the ground. Even if the drone speed changes due to wind or pilot control, the system will still maintain uniform distribution.

Speed-Based Automatic Control: The dispenser can be connected directly to the drone’s GPS and speed data. When the drone moves faster, the drop rate can increase automatically. When it slows down, the drop rate can decrease. This will remove the need for constant manual adjustment by the pilot and improve planting accuracy.

Improved Flow Monitoring: More advanced sensors can be installed to continuously monitor seed movement from the hopper to the gate. This will help in detecting irregular flow conditions early and improving overall drop precision.

2. Advanced Jam Detection and Prevention
Early Jam Prediction System: Instead of waiting for a complete blockage, the controller can study small changes in sensor signals such as delay in seed movement. If it detects unusual patterns, it can take action before a full jam occurs. This will reduce flight time loss and improve mission success rate.

Automatic Self-Clearing Action: The servo gate and V-file can be programmed to perform small periodic shaking movements during operation. These small movements will prevent seed buildup, and lower the chance of seeds getting stuck inside the channel.

Backup Sensor System: Additional IR or small proximity sensors can be placed near the hopper outlet and at the end of the V-file. If one sensor becomes defective or stops working due to dust or mud, the second sensor can continue monitoring the flow. This increases system safety and reliability during real field operations.

3. Hopper Geometry Improvement
Computer-Based Flow Testing: Special software can be used to simulate how seedballs move inside the hopper. This allows engineers to test different wall angles and slot sizes on a computer before building the actual model. It saves time, cost, and improves design accuracy.

Adjustable Slot Mechanism: The slot opening can be made adjustable so that the same system can handle different seedball sizes. This will make the dispenser more flexible for different types of seeds.

Low-Friction Surface Treatment: Applying smooth coatings inside the hopper can reduce sticking, especially when seedballs contain moist soil or clay. This will improve flow consistency and reduce cleaning requirements.

4. Material and Structural Enhancement
Lightweight Strong Materials: In the future, aluminium parts can be replaced with lighter materials such as carbon fiber or reinforced plastic. This will reduce the total weight of the drone and increase flight time.

Better Vibration Control: Improved mounting systems with damping materials can reduce vibration transfer from the dispenser to the drone frame. This will protect electronic components and improve flight stability.

Modular and Easy Maintenance Design: The hopper and V-file assembly can be designed as a detachable unit. This will make cleaning, inspection, and replacement faster and easier during field missions.

5. Autonomous and GPS-Based Seeding
Location-Based Drop Control: By using GPS mapping, the drone can automatically change the seed drop density depending on land type or preloaded data.

Terrain-Based Automatic Adjustment: Cameras or onboard sensors can analyze the land below. The system can then adjust drop rate for forest gaps, farmland, or open land without pilot intervention.

Fully Automatic Operation: The entire mission, including flying and seed dropping, can be automated using flight planning software. This will reduce pilot workload and improve accuracy in large reforestation projects.

6. Scalability and Multi-Mission Adaptability
Multiple Hopper System: Future designs can include more than one hopper working together. This will increase total seed capacity and allow different seed types to be deployed in a single mission.

Cartridge-Based Refilling: Removable seed cartridges can be developed so that refilling becomes quick and simple. This will reduce turnaround time between missions.

Large-Scale Industrial Version: The design can be expanded for bigger drones that carry heavier payloads. This will support large reforestation and agricultural projects.

7. Energy and Power Management
Separate Power System for Electronics: A dedicated power supply for servos and sensors can prevent voltage drops and unexpected system resets during operation.

Smart Battery Monitoring: The system can continuously monitor battery level and adjust drop rate if power becomes low. This ensures safe mission completion and safe return of the drone.

In the future, these improvements can make the seed dispensing system more intelligent, reliable, lightweight, and suitable for large-scale agriculture, reforestation, ecological restoration, and disaster recovery missions.

## 13 Conclusion

In aerial seed dropping, the main challenge is to release only one seedball at a time. Since the seedballs are not of the same size and shape, they may fall together, get stuck, or drop more than one at once. This affects proper spacing and reduces accuracy.
The developed straight-line hopper with dual V-files solves this issue effectively. The hopper is designed with steep wall angles and smooth inner surfaces so that all the seedballs keep moving downward without forming dead zones. A rectangular slot outlet is used instead of a circular hole, which reduces the pressure at the bottom and lowers the chance of arch formation. This slot spreads the seedballs in a line before they enter the V-files, reducing compression and friction between them. The two V-files then guide the seedballs into a single straight path so they do not move side by side. At the end of each V-file, a servo-controlled gate is installed which stays normally closed for safety. An IR sensor checks if a seedball is ready before the gate opens. The servo then performs a quick open–close action to release only one seedball at a time. Overall, the integration of optimized hopper geometry, dual V-file alignment, intelligent sensing, and a precise servo-based gate system results in a compact, lightweight, and reliable dispensing mechanism. The design successfully balances mechanical simplicity, flow physics, and electronic control, making it suitable for safe and efficient aerial reforestation missions.

## References

[1] Darias, J.R., Gella, D., Fernandez, M.E., Zuriguel, I., and Maza, D., 2020. “The hopper angle role on the (https://doi.org/10.1016/j.powtec.2020.116647) ´ velocity and solid-fraction profiles at the outlet of silos.” (https://doi.org/10.1016/j.powtec.2020.116647) Powder Technology, vol. 366, pp. 488–496.
[2] Jenike, A.W., and Johanson, J.R., 1969. “On the Theory of Bin Loads.” (https://doi.org/10.1115/1.3591543) Journal of Engineering for Industry, vol. 91, no. 2, pp. 339–344.
[3] Kidanemariam, A.G., Chan-Braun, C., Doychev, T., and Uhlmann, M., 2013. “Direct numerical simulation of horizontal open channel flow with finite-size, heavy particles at low solid volume fraction.” (https://doi.org/10.1088/1367-2630/15/2/025031) New Journal of Physics, vol. 15, no. 2, 025031.
[4] Bembenek, M., Dmytriv, V., Banha, V., Horodniak, R., and Pawlik, J., 2024. “A Mathematical Model for Conical Hopper Mass Efficiency.” (https://doi.org/10.3390/app14167373) Applied Sciences, vol. 14, no. 16, 7373.
[5] Balevicius, R., Ka ˇ | cianauskas, R., Mr ˇ | oz, Z., and Sielamowicz, I., 2011. “Analysis and DEM simulation of gran- (https://doi.org/10.1016/j.apt.2010.12.001) ´
ular material flow patterns in hopper models of different shapes.” (https://doi.org/10.1016/j.apt.2010.12.001) Advanced Powder Technology, vol. 22, no. 2, pp. 226–235.
[6] Huang, X., Zheng, Q., Liu, D., Yu, A., and Yan, W., 2022. “A design method of hopper shape optimization with improved mass flow pattern and reduced particle segregation.” (https://doi.org/10.1016/j.ces.2022.117579) Chemical Engineering Science, vol. 253, 117579.
[7] Shinohara, K., Idemitsu, Y., Gotoh, K., and Tanaka, T., 1968. “Mechanism of gravity flow of particles from a hopper.” (https://doi.org/10.1021/i160027a006) Industrial & Engineering Chemistry Fundamentals, vol. 7, no. 3, pp. 383–387.

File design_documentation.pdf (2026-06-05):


## Report

Kriti ’26

# Drone Design Challenge

### Hostel ID:

2601


Drone Design Challenge | Kriti ’26

### 1 Introduction

This document provides comprehensive mechanical design documentation for the Seedball Dispenser Module developed as part of the Kriti26 project. The system is a drone-mounted payload designed to autonomously deploy seedballs for aerial reforestation and land restoration applications.

The mechanical assembly comprises five primary sub-components — the Storage Module, the Hopper (with the Hopper with Servo Mounts being its detailed production-ready iteration), the V-File Channel, and the Connection Bracket — all designed in Autodesk Fusion 360 and manufactured to meet the dimensional tolerances specified within the engineering drawings.

### 1.1 Purpose of This Document

This design documentation serves as the primary reference for the mechanical sub-system, intended for use by the manufacturing team, integration engineers, and future maintainers. It covers:

- Functional description of each sub-component
- Dimensional specifications and tolerances extracted from engineering drawings
- Bounding volume and mesh complexity data from CAD files
- Assembly relationships and interface definitions
- File format inventory and CAD file structure
- Design rationale, constraints, and assumptions
- Manufacturing and assembly guidelines

### 1.2 Scope

This document covers only the mechanical design of the dispensing module. Electronics integration (ESP32 firmware, servo wiring, IR sensor placement), ROS 2 simulation, and flight controller integration are documented separately in their respective sub-system documents.

### 1.3 Document Conventions

All linear dimensions in this document are expressed in millimetres (mm) unless otherwise stated. Angular dimensions are expressed in degrees (°). Tolerances are expressed in the ± format as defined in the engineering drawings. File paths use forward slashes and are relative to the project root.

### 2 System Architecture & Design Intent

### 2.1 Functional Overview

The Seedball Dispenser Module is a gravity-assisted dispensing mechanism. Seedballs are pre-loaded into the storage hopper prior to flight. During operation, the ESP32 microcontroller receives a drop command via UART from the onboard computer (Jetson/Raspberry Pi) and actuates one of two servo-controlled gates at the base of the hopper. Gravity causes seedballs to exit the hopper through a V-shaped channel that guides them to the drop point. IR sensors along the channel and at the neck confirm successful dispensing and detect jams.

The dual-file design (File A / File B, corresponding to Servo A and Servo B) allows the system to switch to a secondary channel if the primary becomes jammed, increasing mission reliability without requiring a physical

intervention.

### 2.2 Design Principles

- Lightweight construction: Core structural components are fabricated from Aluminium Alloy (4xx.x Series), providing an optimal strength-to-weight ratio. The total calculated mass of the hopper assembly is restricted to an optimised 2.85 kg.
- Modularity: Each sub-component is independently replaceable. Standardised mating flanges and fastener interfaces allow sub-components to be re-cast or re-formed individually without disassembling the full stack.
- Gravity-fed operation: No additional actuators are required for ball transport; only the gate servos consume power.
- Dual-channel redundancy: Two independent dispensing files extend operational continuity during jams.
- Tool-free assembly: Connection brackets and mounting interfaces are designed for snap-fit or screw-based assembly accessible without specialised tooling.

### 2.3 Mechanical Sub-System Hierarchy

The full assembly is composed of five interacting sub-assemblies arranged in a vertical stack:

# | Sub-Component | Role in Assembly | CAD File

1 | Storage Module | Top-level bulk storage reservoir for seedballs | 03_STORAGE.f3d
2 | Hopper | Collects and funnels balls from storage to gate | 01_HOPPER.f3d
2a | Hopper with Servo Mounts | Production-ready iteration of the Hop-per — same base geometry with inte-grated servo mounting detail | 02_HOPPER_WITH-SERVO -MOUNTS.f3d
4 | V-File Channel | Dual V-shaped guide channel directing balls to exit | 04_V-FILE.f3d
5 | Connection Bracket | Structural interface connecting module to drone frame | 05_CONNECTION.f3d

Table 1: CAD Sub-Components

### 3 Component Design Specifications

### 3.1 Storage Module

The Storage Module is the topmost component in the assembly stack. It serves as the primary seedball reservoir, holding the full payload of balls prior to dispensing. The module interfaces with the Hopper below it via a mating flange, allowing balls to feed through under gravity.

### 3.1.1 Dimensional Specifications

Parameter | Value | Tolerance
Overall Width (X) | 294.7 mm | ±0.5 mm
Overall Depth (Y) | 317.5 mm | ±0.5 mm
Overall Height (Z) | 105.0 mm | ±0.3 mm
Front Face Width | 295 mm | ±0.5 mm
Side Panel Depth | 317.5 mm | ±0.5 mm
Bottom Opening Width | 160 mm | ±0.4 mm
Mounting Hole Diameter | Ø6.5 mm | —
Hole Offset from Edge | 17.5 mm | —

The storage module features a rectangular cross-section with a tapered internal floor to direct balls toward the central outlet. The Ø6.5 mm mounting holes positioned 17.5 mm from the edge provide the structural connection to the hopper body below.

### 3.2 Hopper / Hopper with Servo Mounts

The Hopper and the Hopper with Servo Mounts share the same base CAD geometry. The Hopper (01_HOPPER) represents the foundational design, while the Hopper with Servo Mounts (02_HOPPER_WITH-SERVO-MOUNTS) is the fully detailed, production-ready iteration — it adds integrated servo mounting bosses to the base body without altering the core hopper geometry. The Hopper with Servo Mounts is the version used in the final assembly.

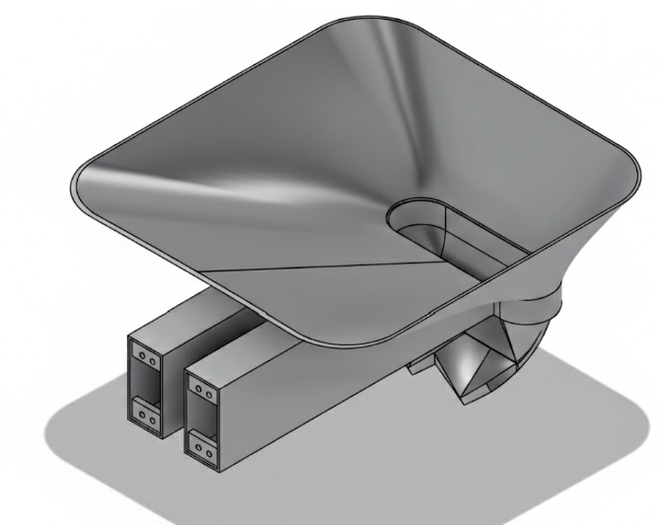
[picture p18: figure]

Figure 1: Hopper with servo mount

The Hopper receives seedballs from the Storage Module and funnels them into the dual-file channel. Its angled internal walls are designed to prevent bridging — a common failure mode in granular dispensers where balls interlock and block the outlet. The geometry transitions from a wide rectangular input at the top to a narrower rectangular exit at the base.

### 3.2.1 Dimensional Specifications — Base Hopper (01_HOPPER)

Parameter | Value | Tolerance
Overall Width (X) | 294.7 mm | ±0.5 mm
Overall Depth (Y) | 317.5 mm | ±0.5 mm
Overall Height (Z) | 133.1 mm | —
Top Opening Width | 295 mm | ±0.5 mm
Base Width | 317 mm | ±0.5 mm
Wall Taper Angle | 53.0° ±0.7° / 57.5° ±1° | ±1°
Bottom Flat Width | 50 mm | —
Side Reference Dim | 150 mm | ±0.4 mm
Internal Radius (base corner) | R23 mm | —

The dual-angle internal walls (53° and 57.5°) were selected based on the expected diameter range of seedballs (15–30 mm) to ensure reliable flow without compaction. The R23 mm internal radius at the hopper base reduces stress concentrations and prevents ball jamming at the outlet corner.

### 3.2.2 Hopper with Servo Mounts — Additional Dimensions

The following dimensions apply specifically to the Hopper with Servo Mounts (02_HOPPER_WITH-SERVO-MOUNTS), reflecting the additional servo mounting geometry added to the base hopper body.

### 3.2.3 Servo Mount Interface Notes

Parameter | Value | Tolerance
Overall Width (X) | 294.7 mm | ±0.5 mm
Overall Depth (Y) | 335.4 mm | ±0.5 mm
Overall Height (Z) | 213.2 mm | —
Mount Plate Width | 156 mm | ±0.4 mm
Upper Body Width | 263.6 mm | ±0.5 mm
Servo Hole Diameter | Ø4.5 mm | —
Mount Hole Spacing A | 94 mm | —
Mount Hole Spacing B | 96 mm | —
Bracket Tab Height | 34 mm | —
Bracket Tab Depth | 10 mm | —
Mount Offset from Top | 21 mm | —

The Ø4.5 mm servo mounting holes are sized for M4 bolts or self-tapping screws commonly used with standard SG90/MG90S class servos. The 94 mm and 96 mm hole spacings correspond to the standard servo body dimensions, ensuring compatibility with off-the-shelf servo hardware without modification.
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

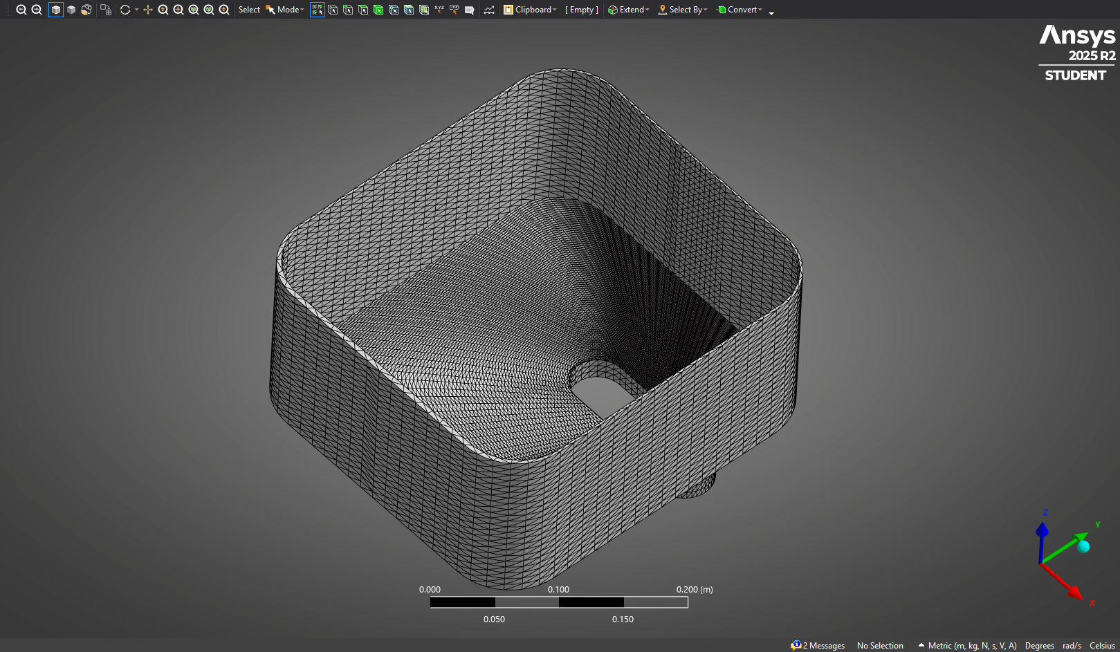
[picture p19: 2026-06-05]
04_ANALYSIS/mesh.png

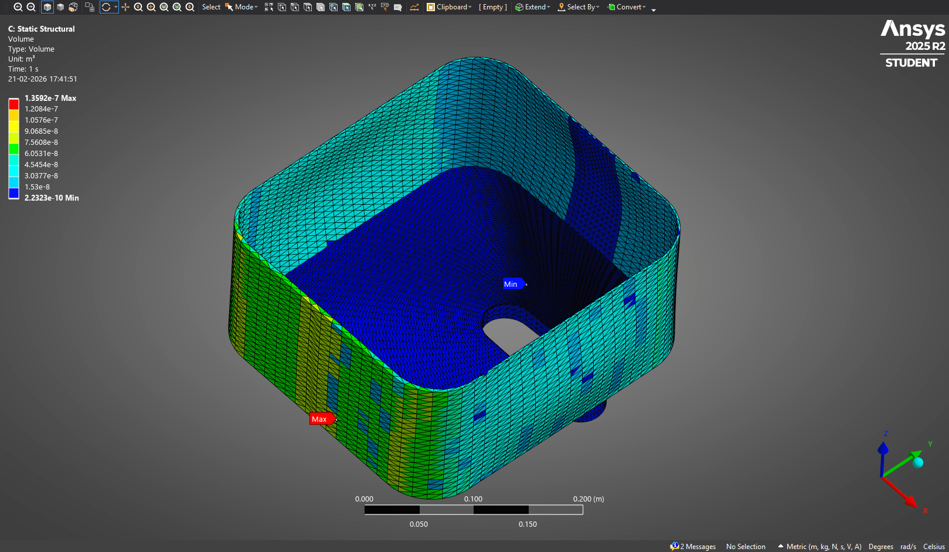
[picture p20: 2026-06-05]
04_ANALYSIS/volume.png

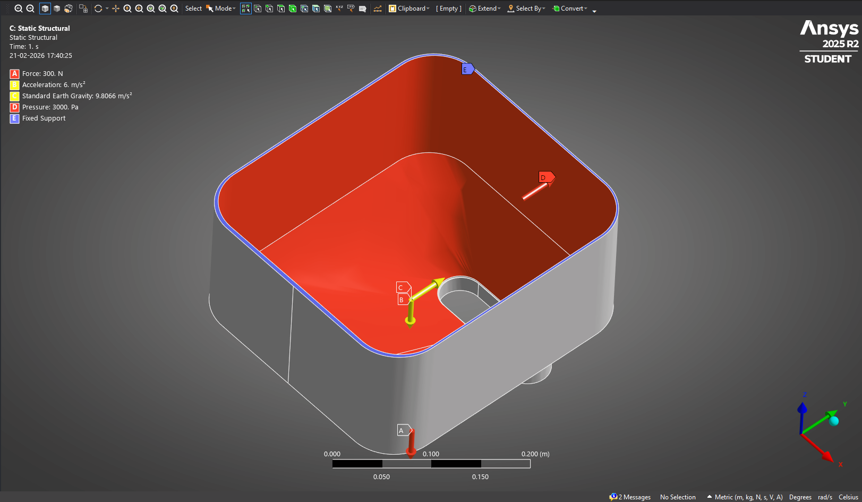
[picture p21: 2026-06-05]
04_ANALYSIS/forces.png

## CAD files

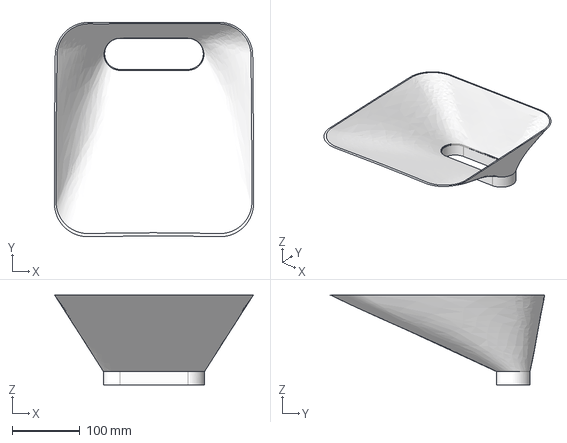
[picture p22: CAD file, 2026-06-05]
01_CAD_FILES/01_HOPPER.step
294.6 x 317.3 x 133.1 mm

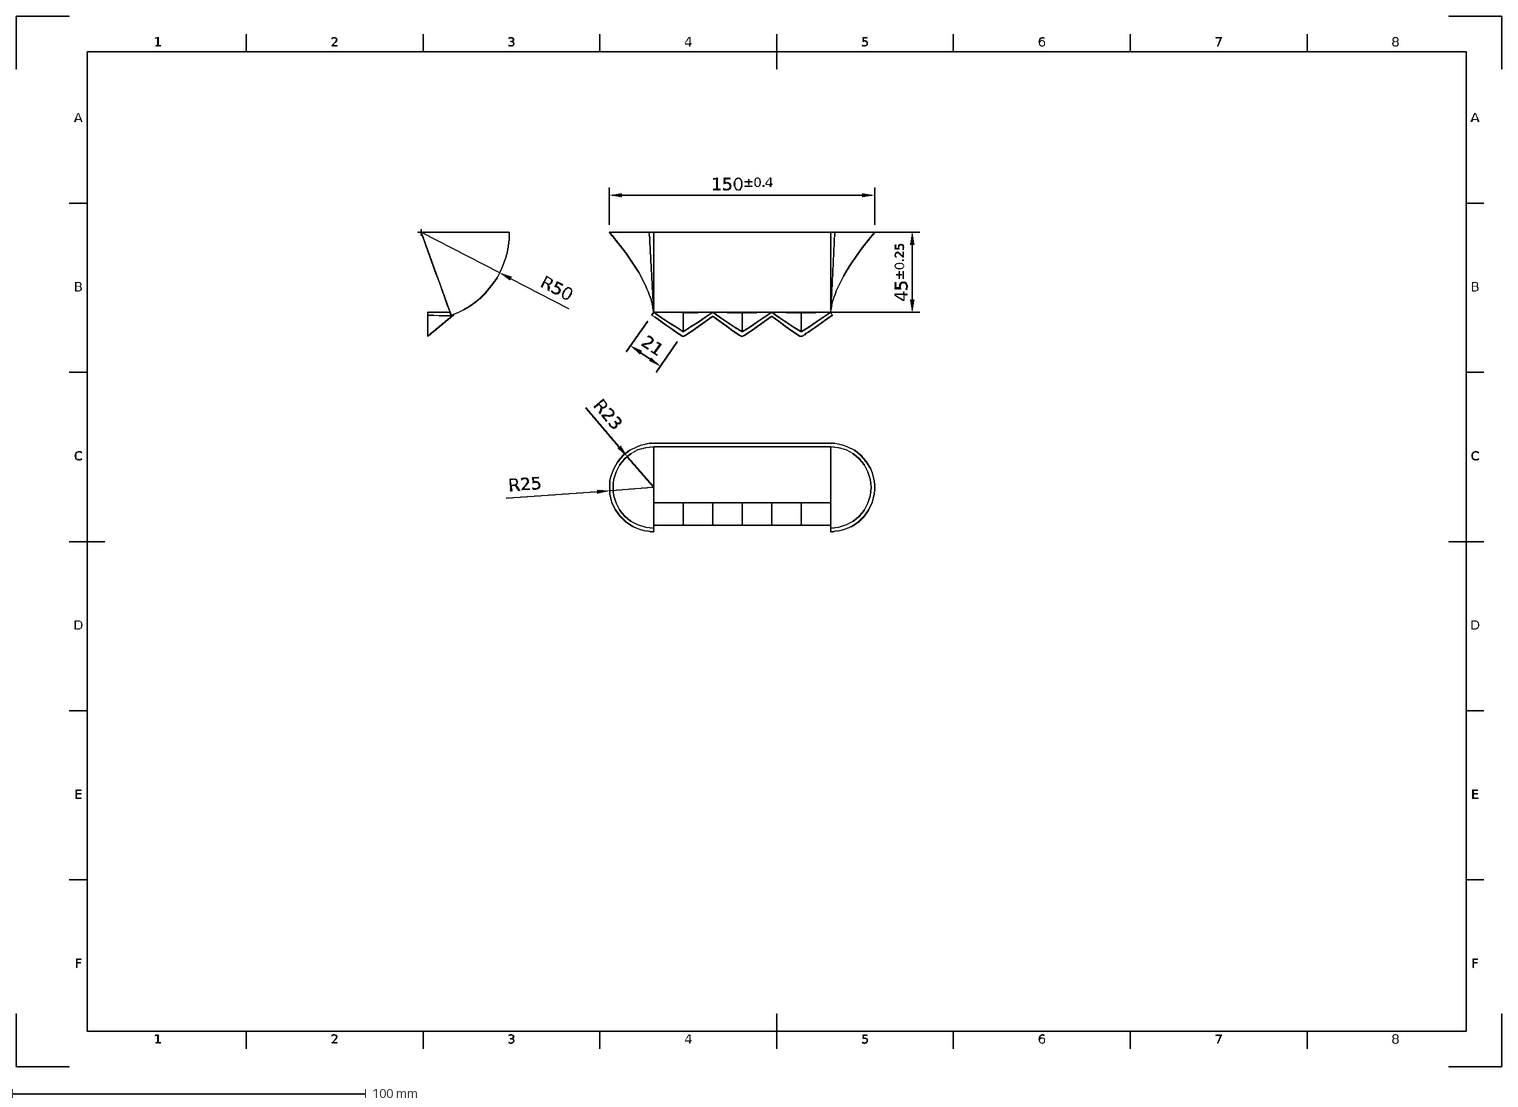
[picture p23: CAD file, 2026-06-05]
02_DRAWING/05_CONNECTION.dxf
1
A
2
3
4
5
6
7
8
B
C
D
E
F
150±0.4
45±0.25
R50
R25
R23
21

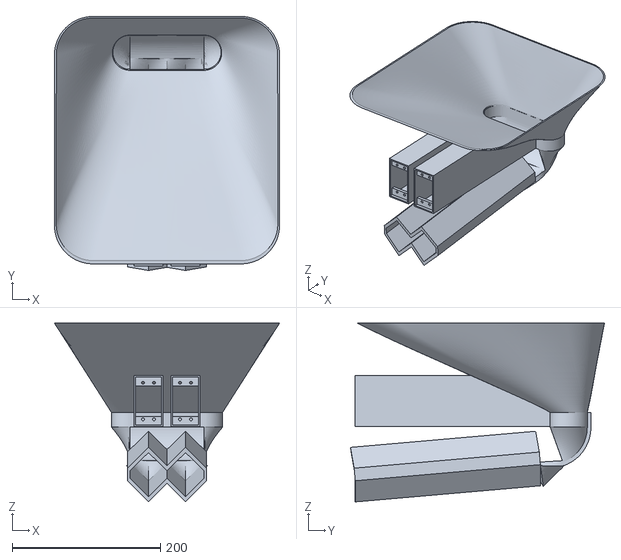
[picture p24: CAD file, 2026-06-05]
03_SIMULATIONS/src/my_robot_description/meshes/base_link.stl
304.0 x 343.0 x 241.5

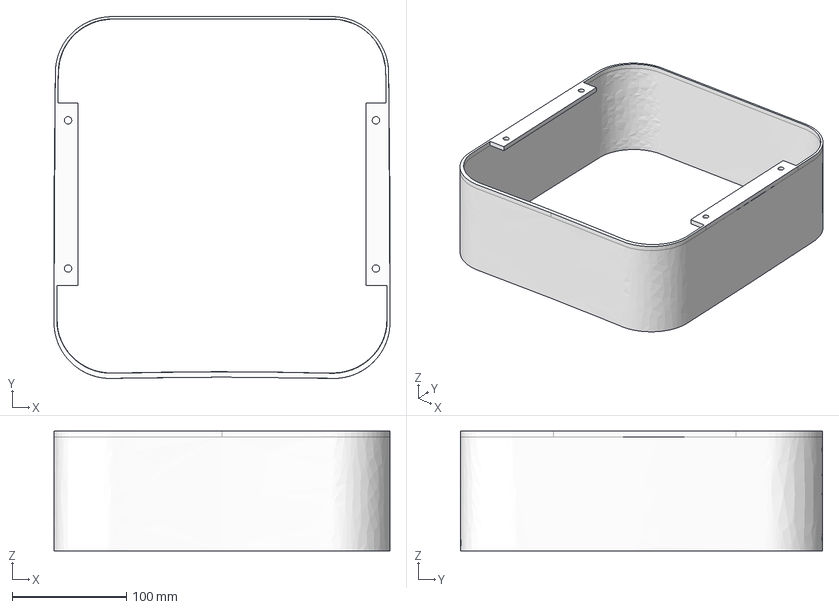
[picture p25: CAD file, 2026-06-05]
01_CAD_FILES/03_STORAGE.step
294.7 x 317.5 x 105.0 mm

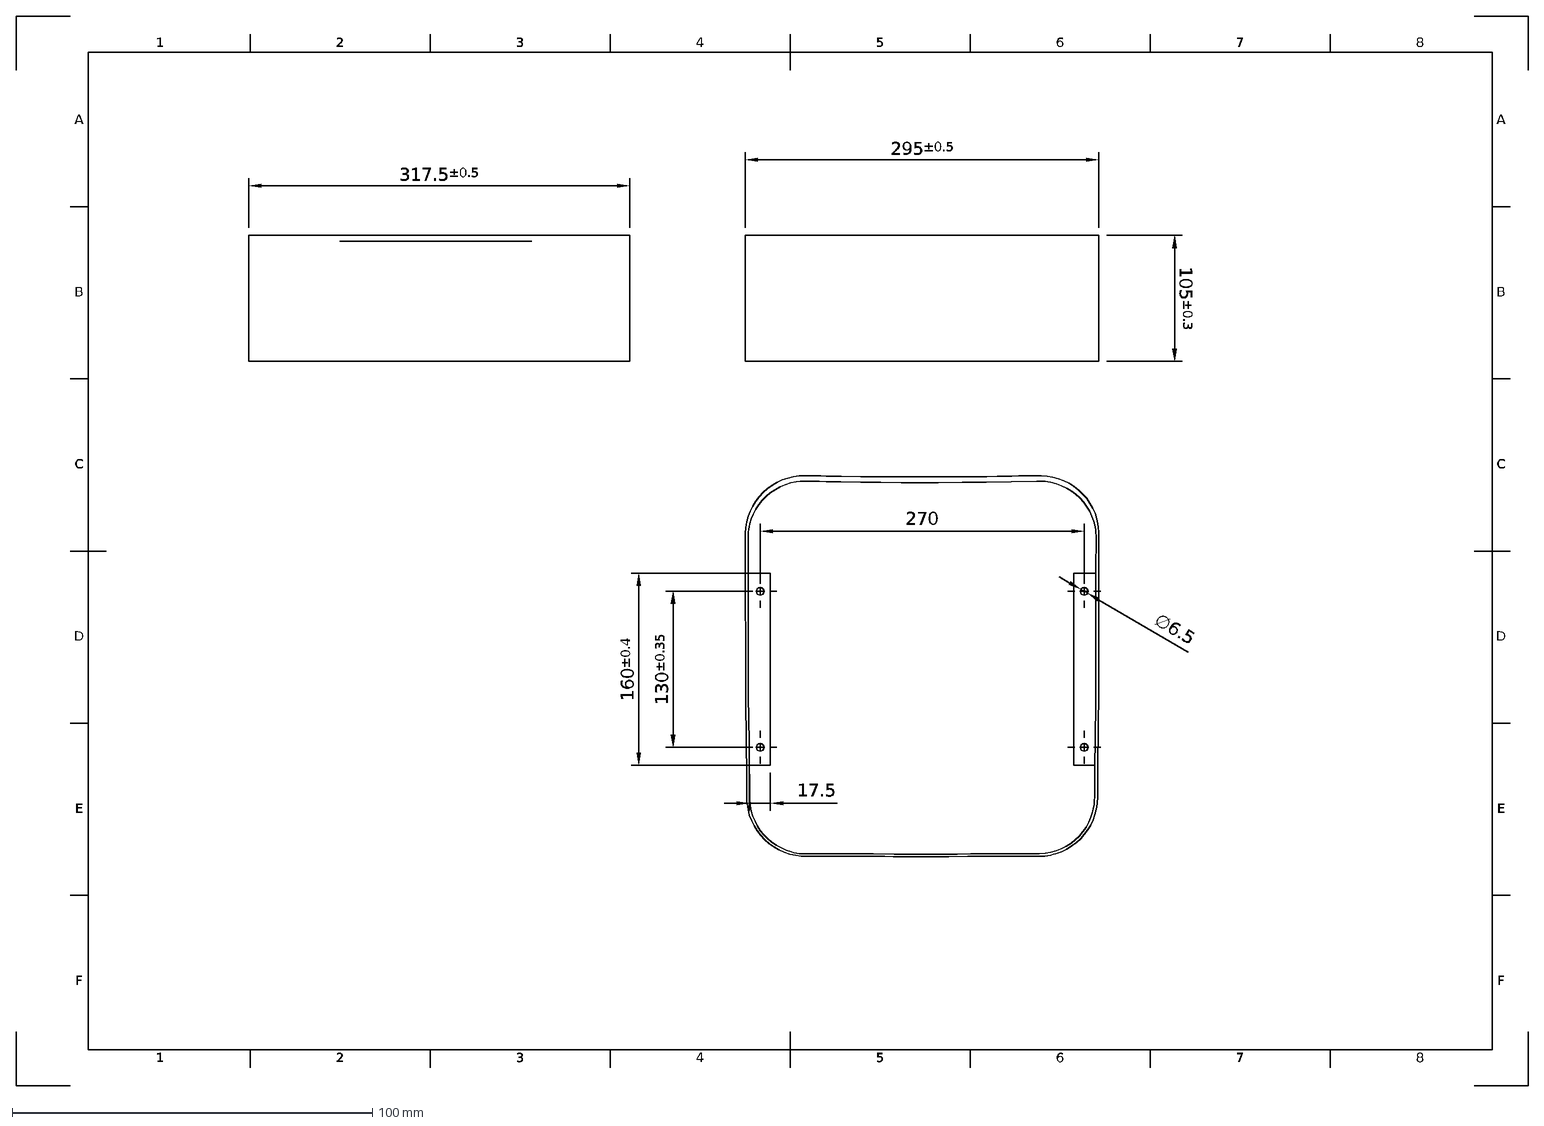
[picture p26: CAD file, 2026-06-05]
02_DRAWING/03_STORAGE.dxf
1
A
2
3
4
5
6
7
8
B
C
D
E
F
295±0.5
105±0.3
270
130±0.35
160±0.4
17.5
317.5±0.5
∅6.5

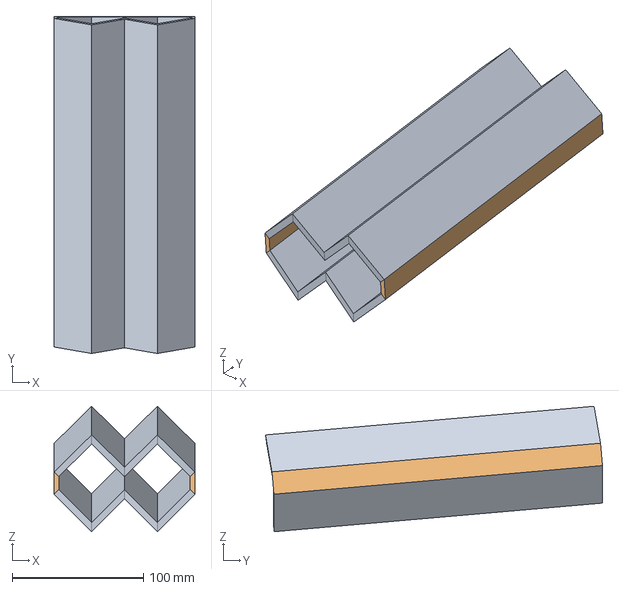
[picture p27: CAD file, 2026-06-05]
01_CAD_FILES/04_V-FILE.step
107.1 x 256.4 x 95.4 mm

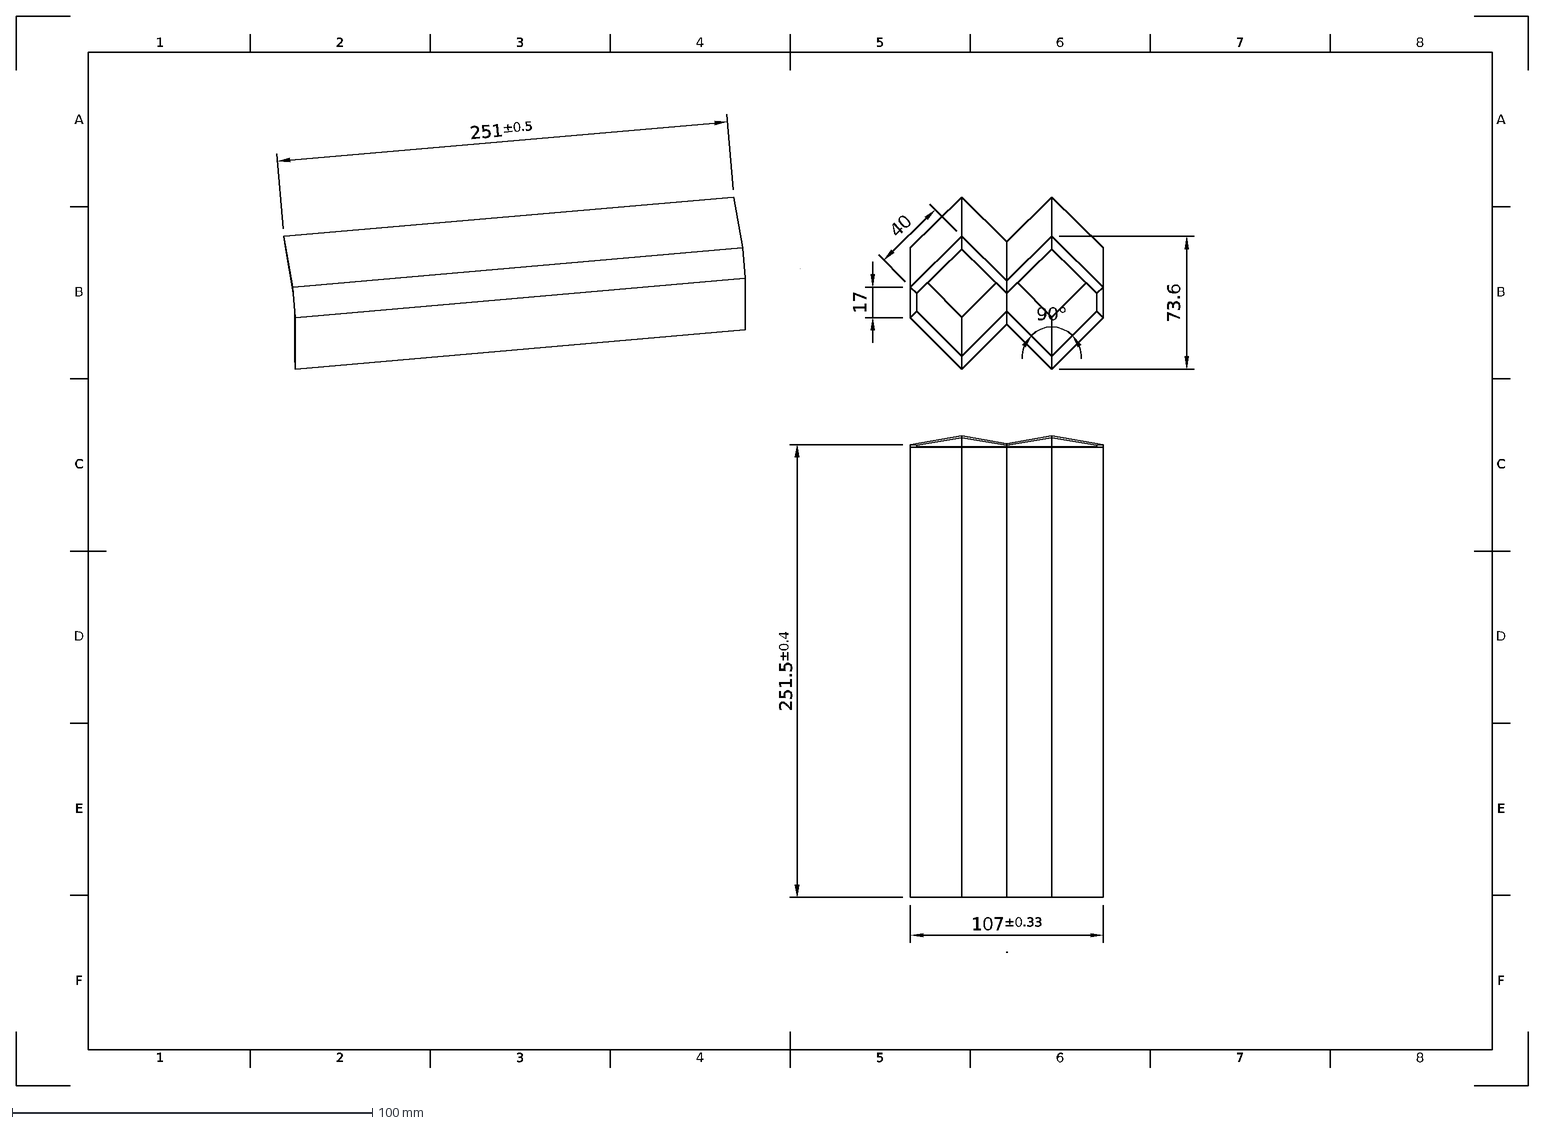
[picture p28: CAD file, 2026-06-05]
02_DRAWING/04_V-FILE.dxf
1
A
2
3
4
5
6
7
8
B
C
D
E
F
73.6
251.5±0.4
251±0.5
107±0.33
90°
40
17

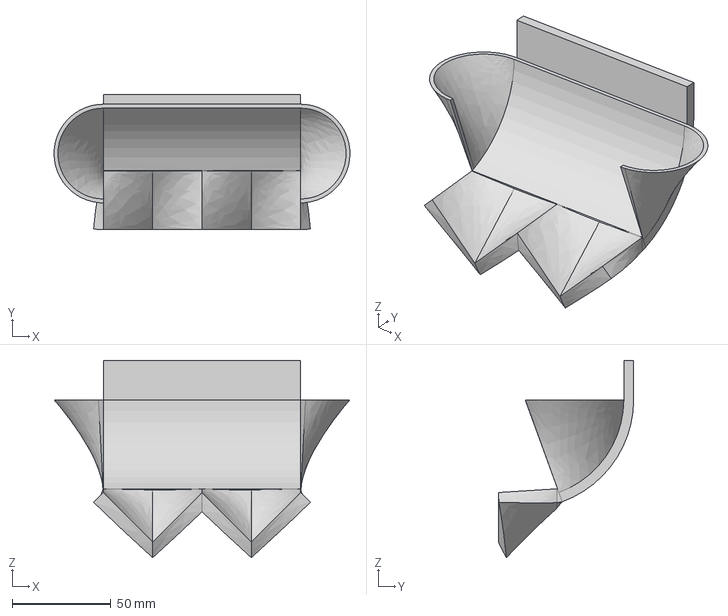
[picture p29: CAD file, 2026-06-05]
01_CAD_FILES/05_CONNECTION.step
150.0 x 68.6 x 100.0 mm

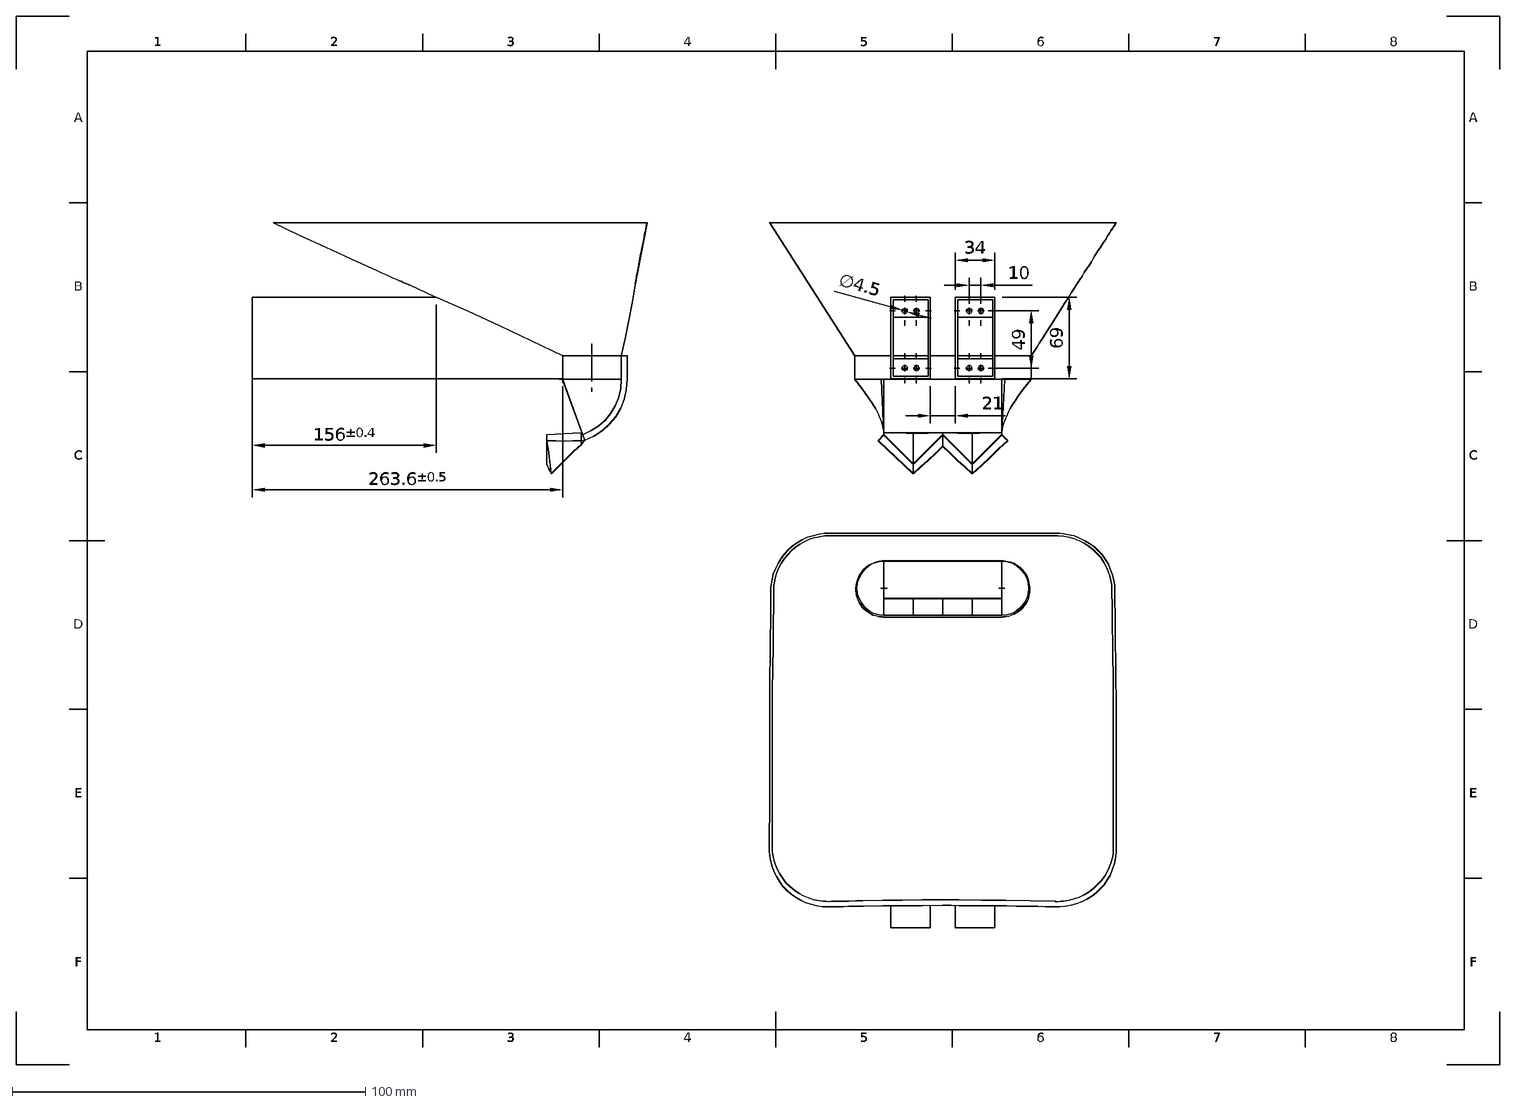
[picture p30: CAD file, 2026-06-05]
02_DRAWING/02_HOPPER_WITH-MOUNTS.dxf
1
A
2
3
4
5
6
7
8
B
C
D
E
F
263.6±0.5
156±0.4
∅4.5
10
49
69
34
21

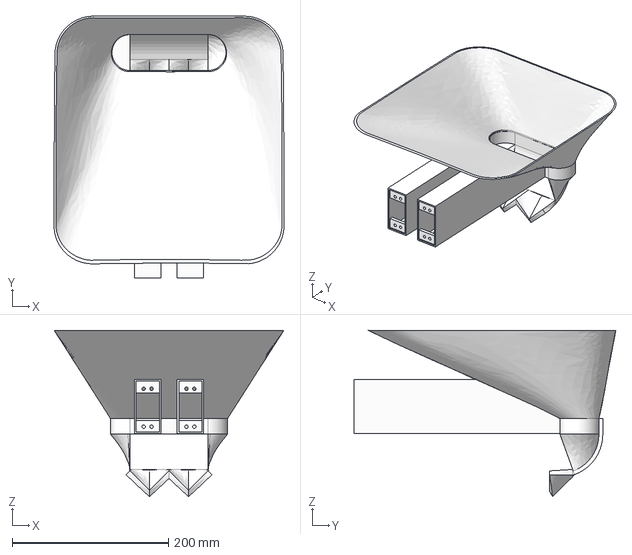
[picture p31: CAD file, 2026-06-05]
01_CAD_FILES/02_HOPPER_WITH-SERVO-MOUNTS.step
294.6 x 335.3 x 213.2 mm

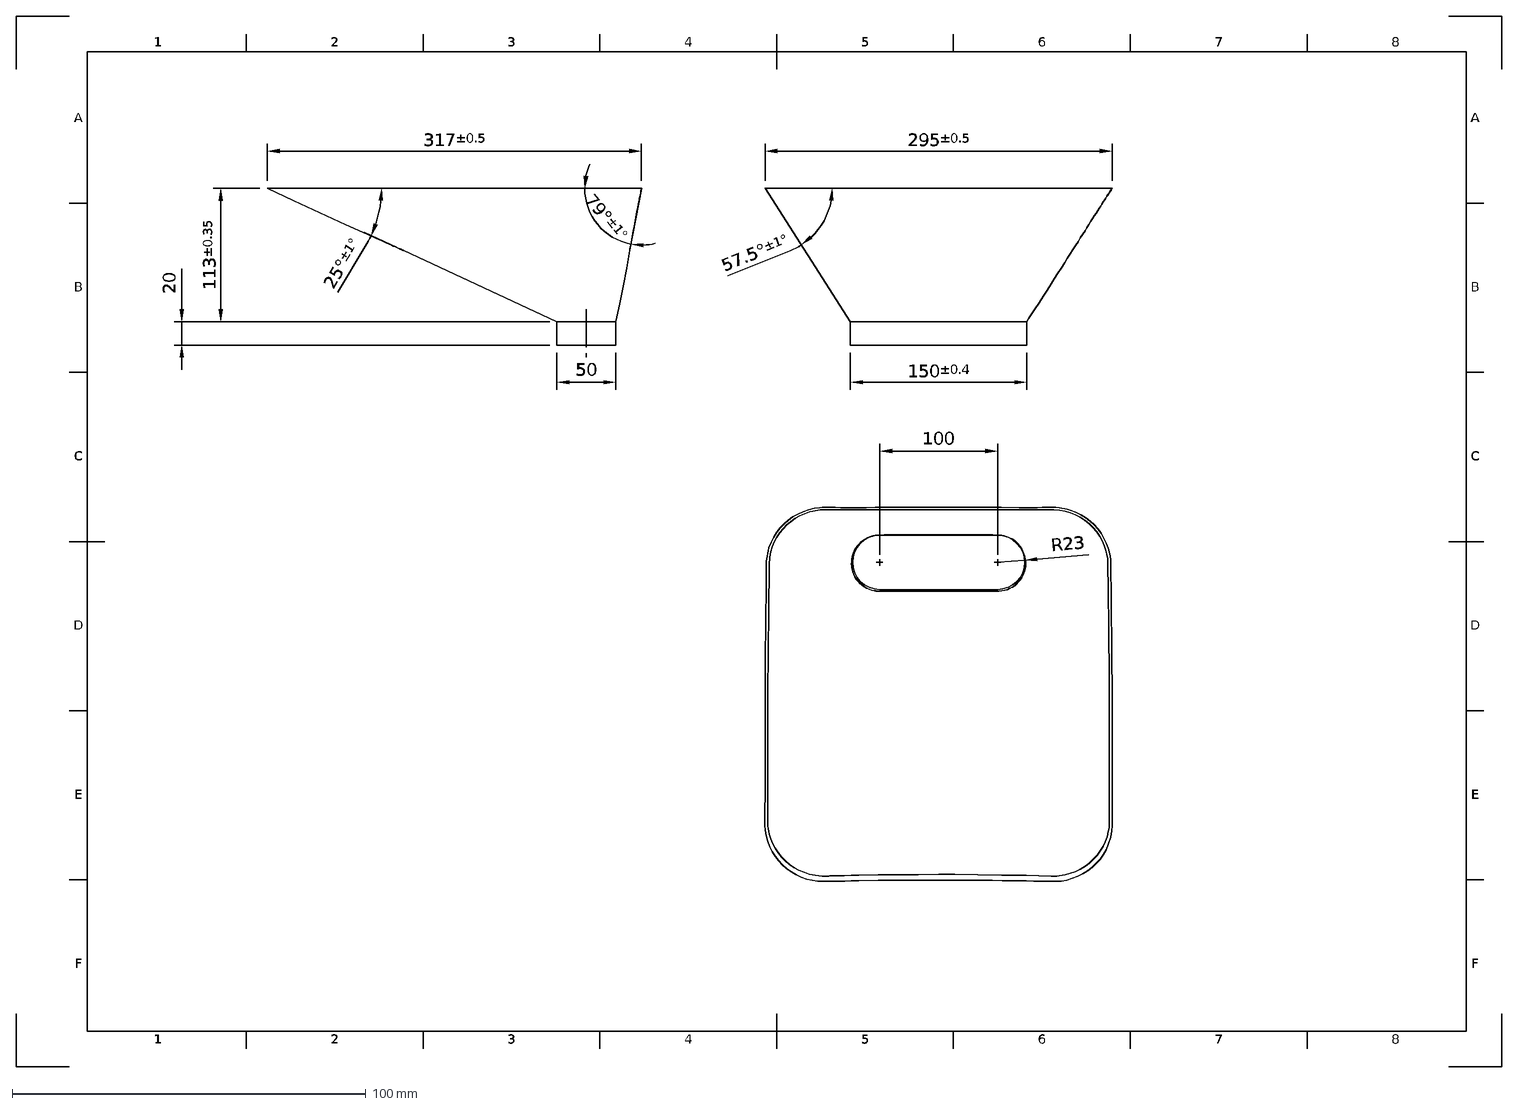
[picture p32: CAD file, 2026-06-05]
02_DRAWING/01_HOPPER.dxf
1
A
2
3
4
5
6
7
8
B
C
D
E
F
295±0.5
317±0.5
113±0.35
20
25°±1°
79°±1°
50
150±0.4
100
R23
57.5°±1°

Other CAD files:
01_CAD_FILES/00_FULL-ASSEMBLY.f3z
01_CAD_FILES/01_HOPPER.f3d
01_CAD_FILES/01_HOPPER.stl
01_CAD_FILES/02_HOPPER_WITH-SERVO-MOUNTS.f3d
01_CAD_FILES/02_HOPPER_WITH-SERVO-MOUNTS.stl
01_CAD_FILES/03_STORAGE.f3d
01_CAD_FILES/03_STORAGE.stl
01_CAD_FILES/04_V-FILE.f3d
01_CAD_FILES/04_V-FILE.stl
01_CAD_FILES/05_CONNECTION.f3d
01_CAD_FILES/05_CONNECTION.stl

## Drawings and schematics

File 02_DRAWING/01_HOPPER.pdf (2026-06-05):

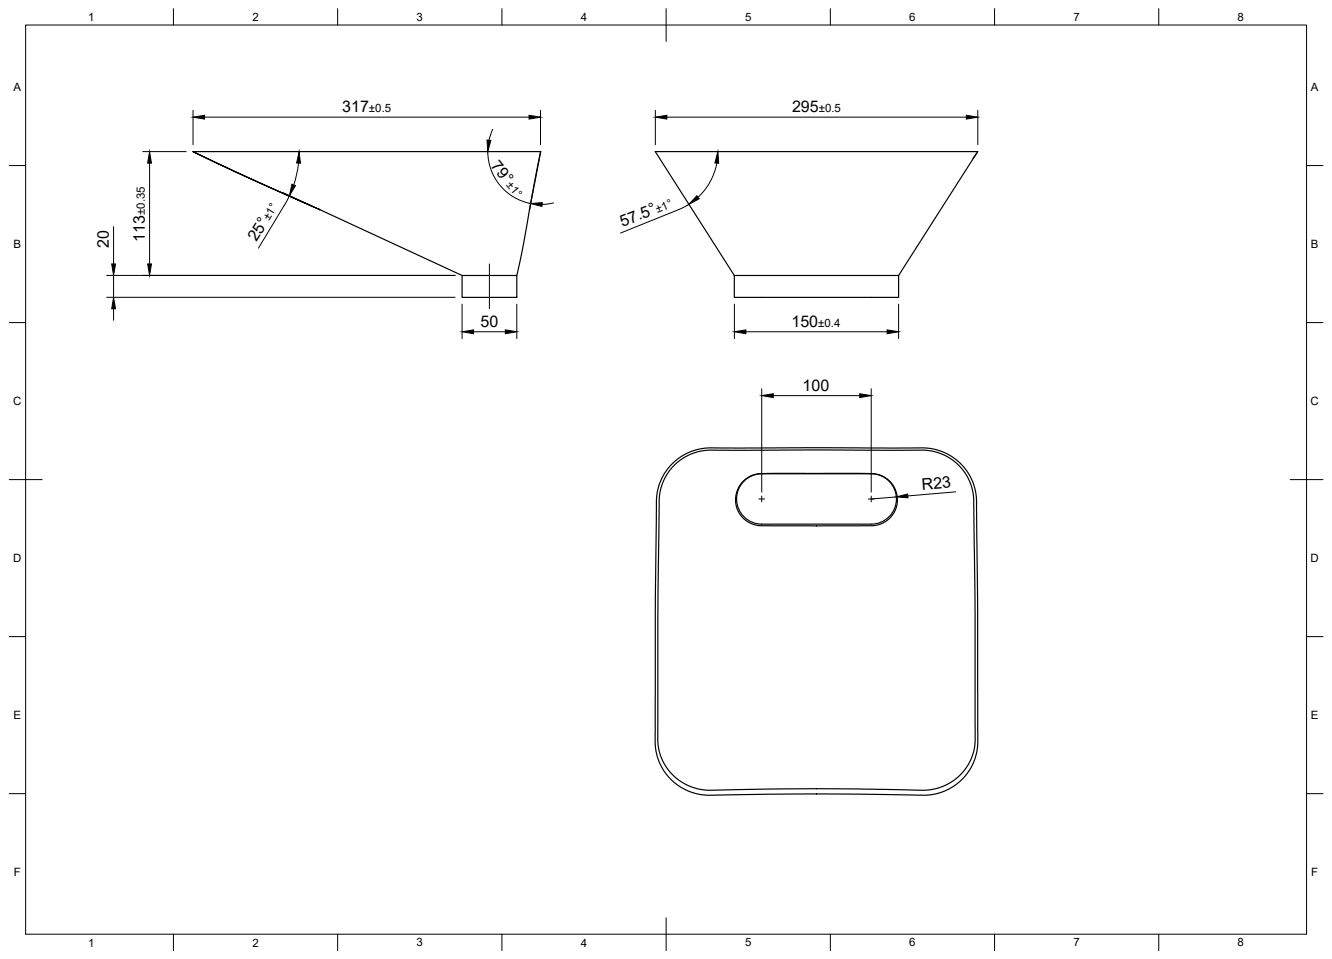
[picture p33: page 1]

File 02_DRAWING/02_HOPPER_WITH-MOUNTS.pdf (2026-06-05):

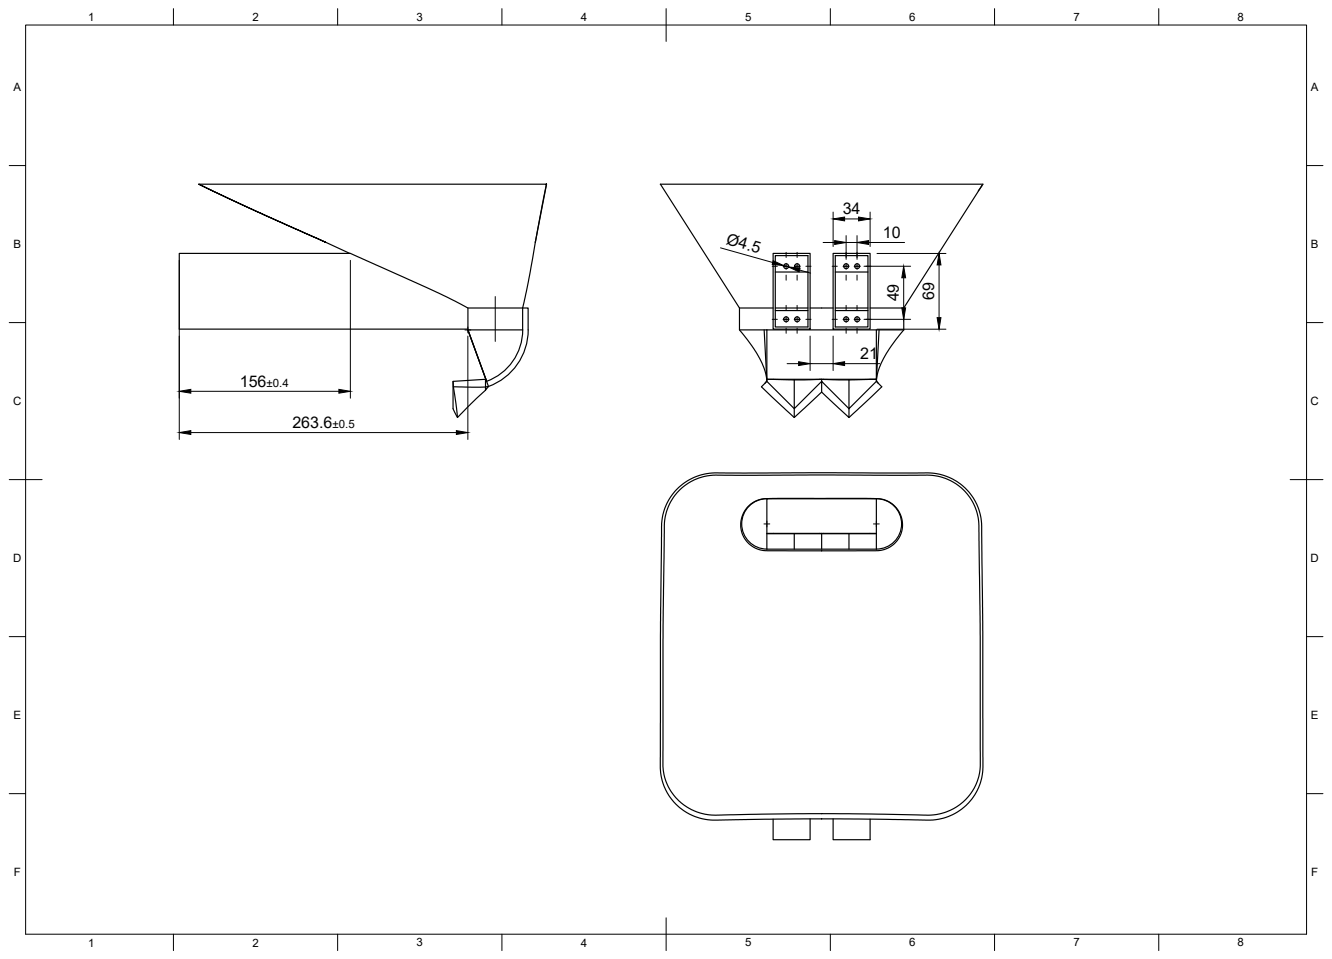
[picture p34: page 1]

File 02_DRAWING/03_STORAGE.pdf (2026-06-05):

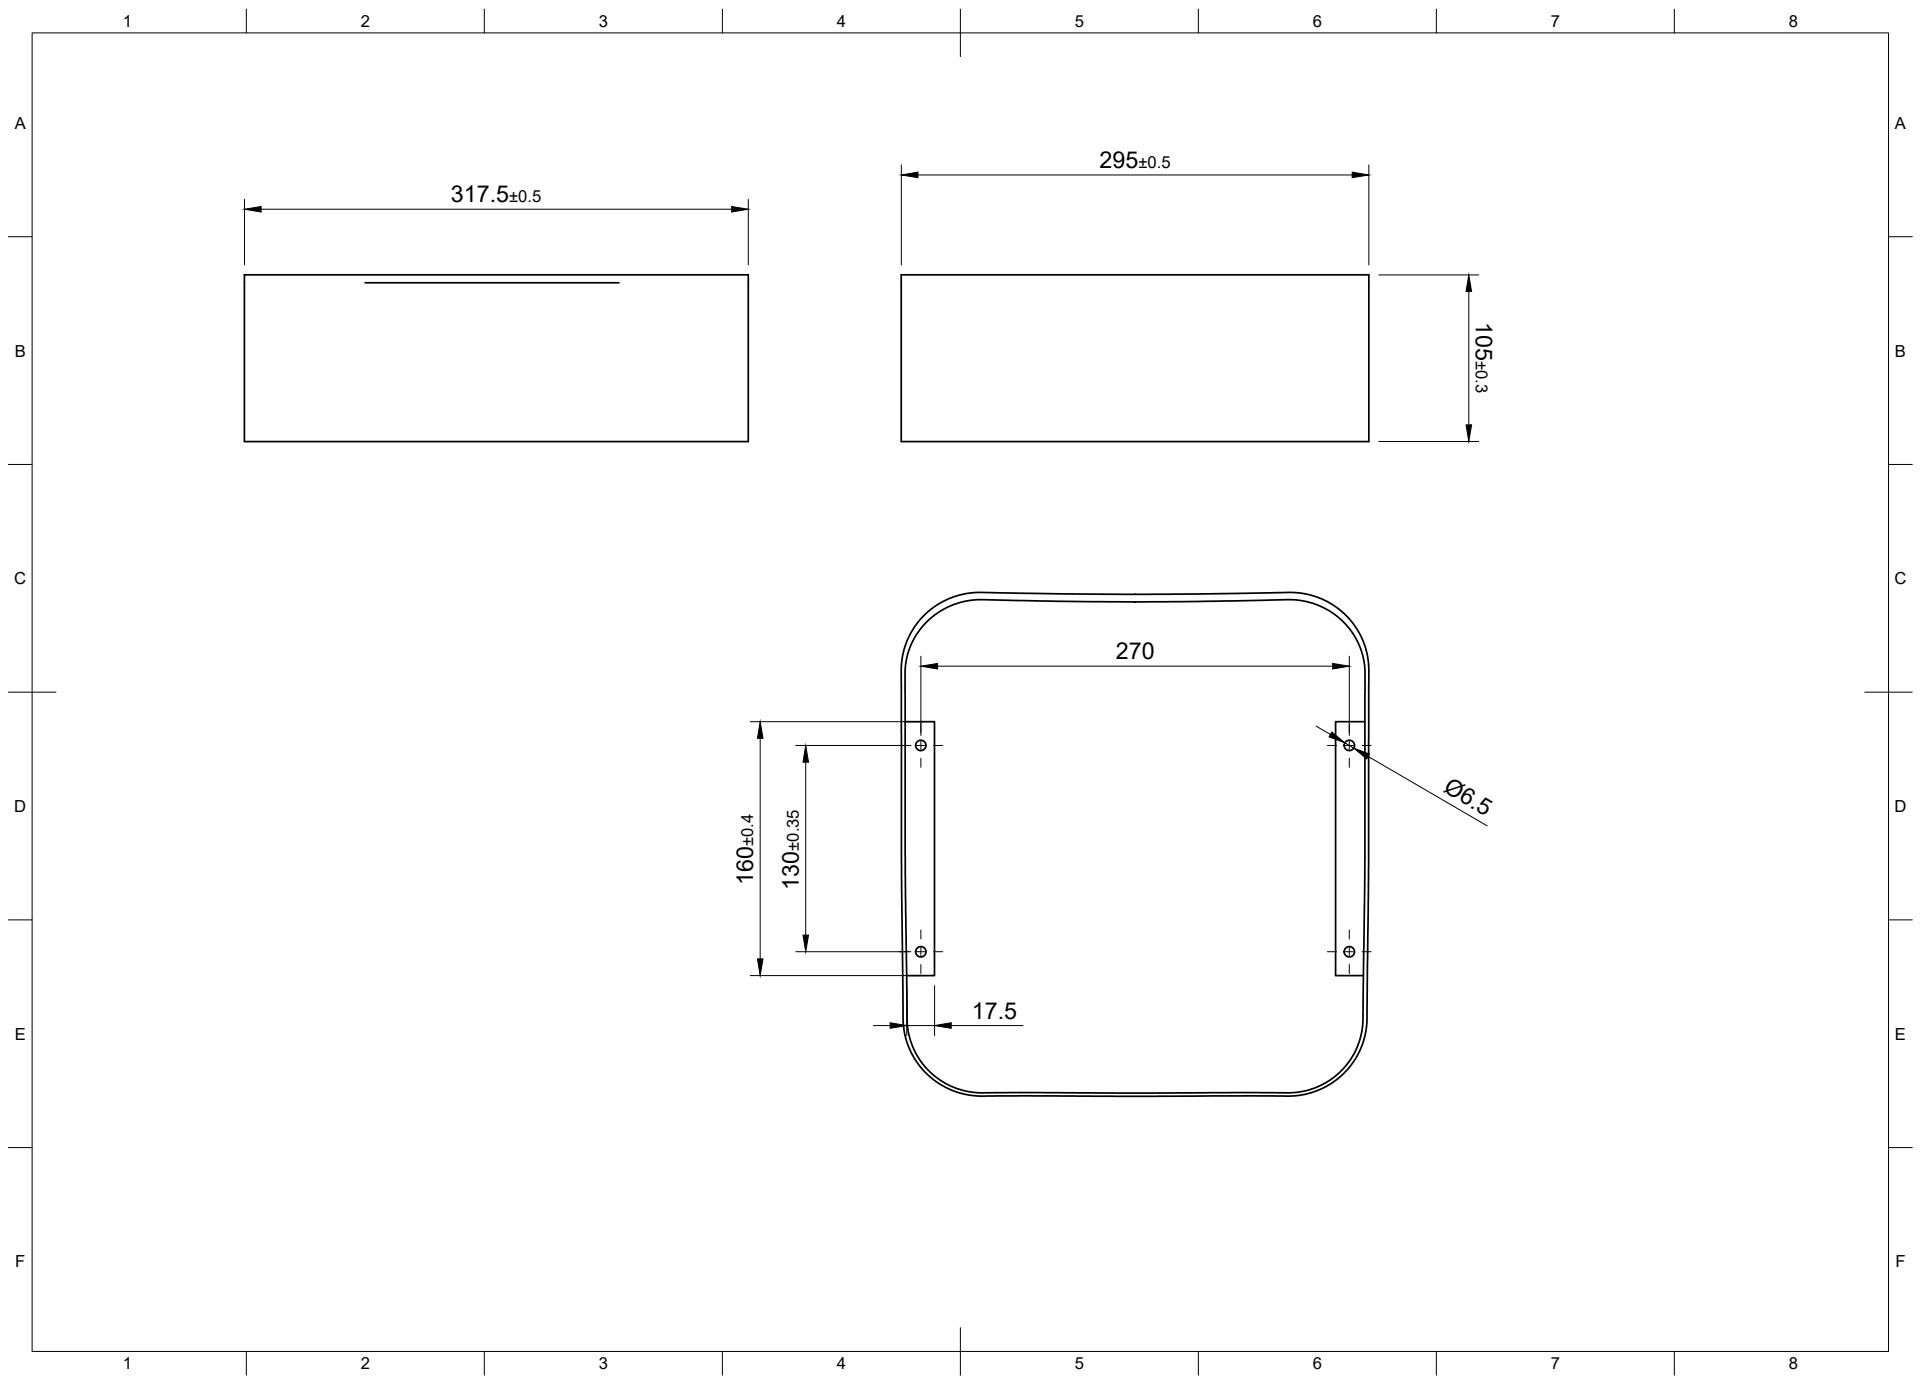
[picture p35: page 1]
8 BCDEF; ABCDEF

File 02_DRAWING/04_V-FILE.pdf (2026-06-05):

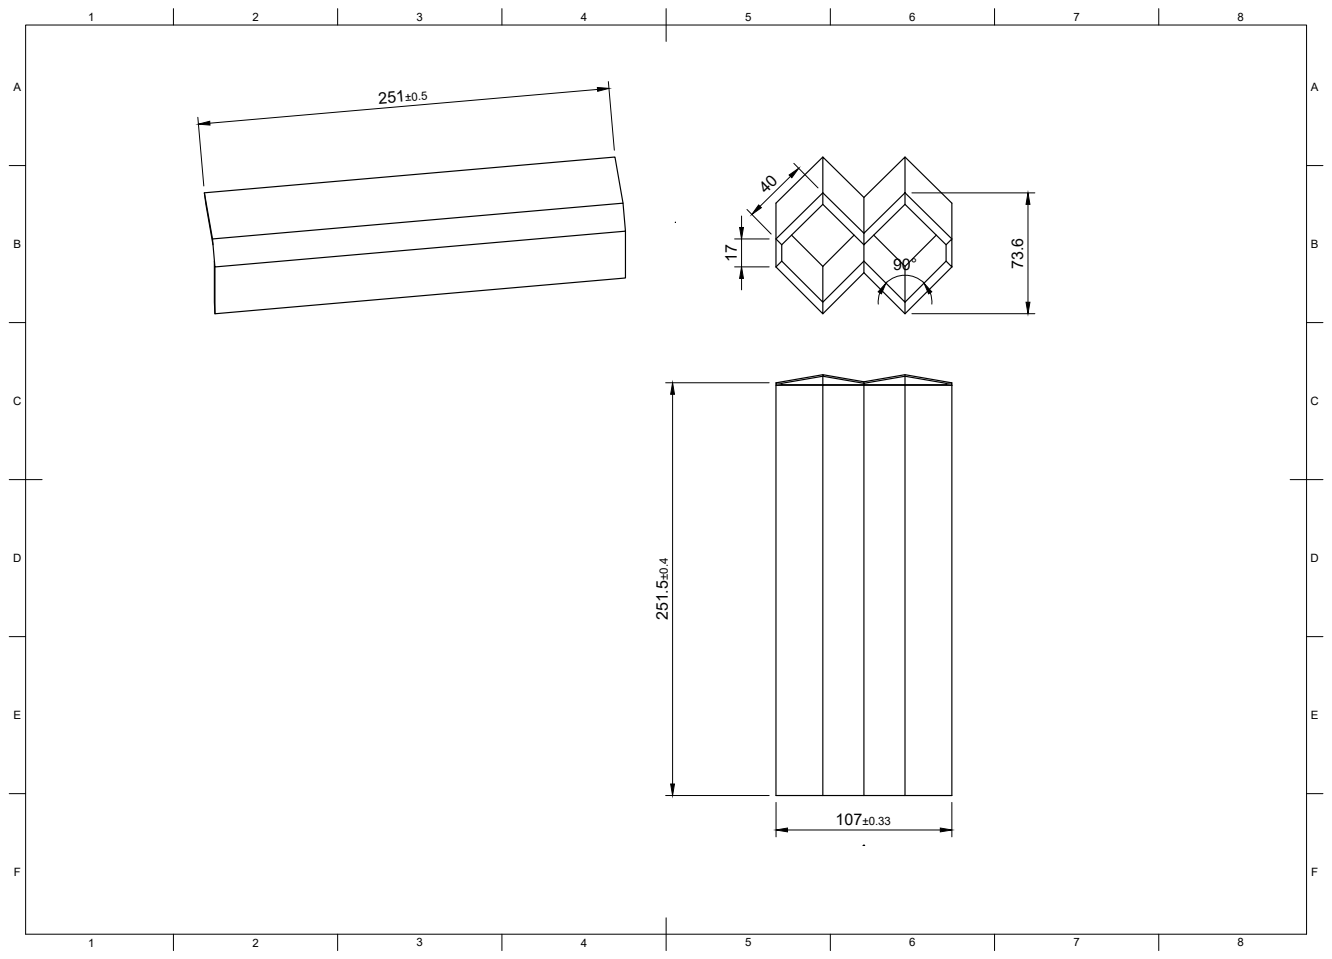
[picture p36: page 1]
8 BCDEF; ABCDEF 73.6 251.5±0.4

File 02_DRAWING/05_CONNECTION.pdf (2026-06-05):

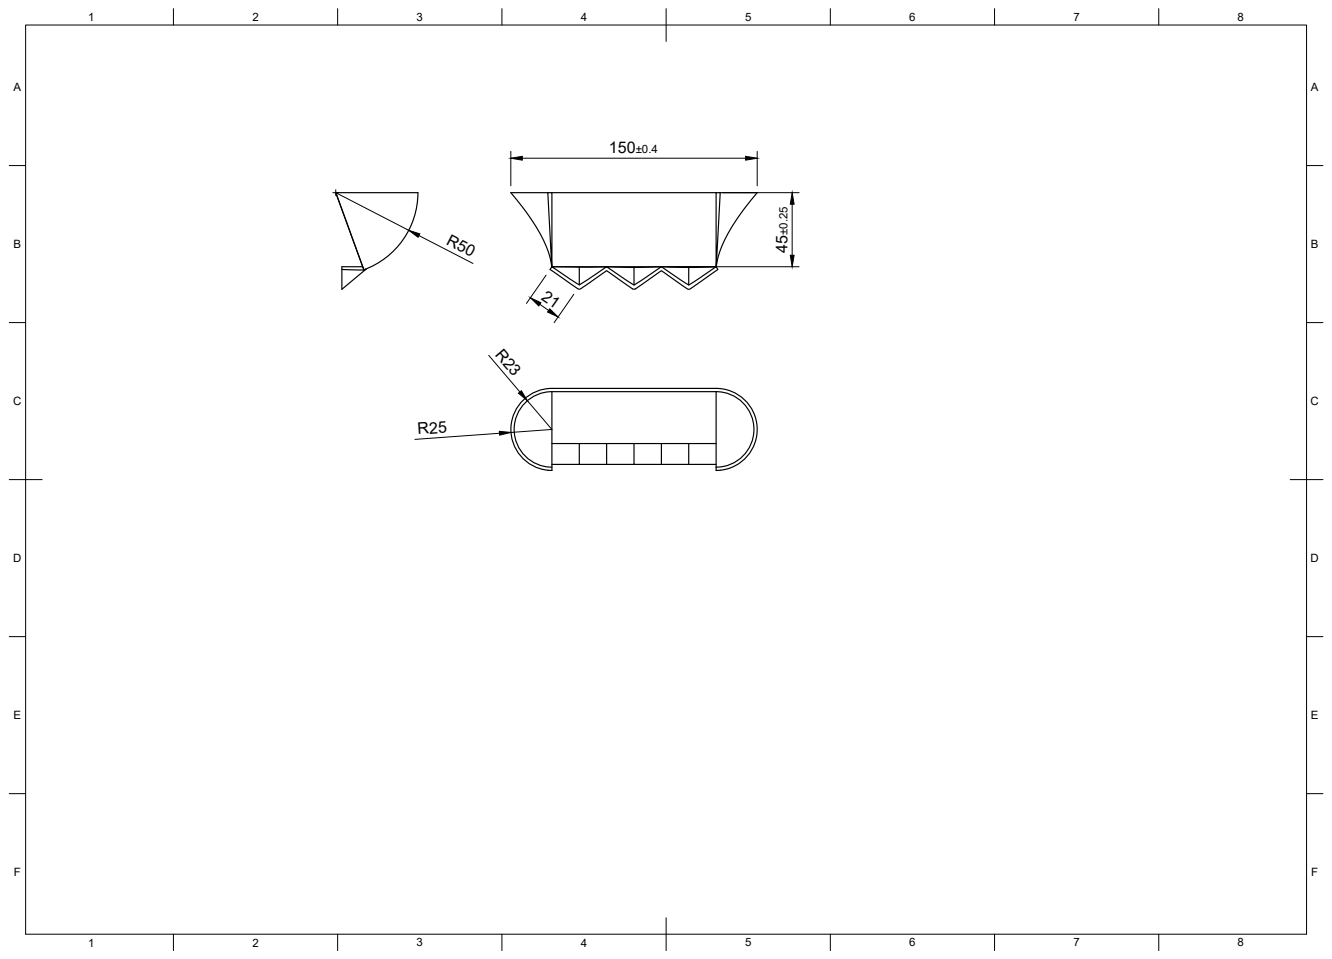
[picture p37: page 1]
8 BCDEF; ABCDEF

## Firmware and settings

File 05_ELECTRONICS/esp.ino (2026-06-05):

// =========================================================================
// INTEGRATED SEEDBALL DISPENSER & MAVLINK TELEMETRY SYSTEM (UART/WIRED VERSION)
// =========================================================================

#include <ESP32Servo.h>
#include "mavlink/ardupilotmega/mavlink.h" 

// --- MAVLINK CONFIGURATION ---
const uint8_t SYSTEM_ID = 1;     
const uint8_t COMPONENT_ID = 1;  
unsigned long lastMavlinkTime = 0;

// --- ORIGINAL HARDWARE PIN CONFIGURATION ---
const int SERVO_A_PIN = 22;
const int SERVO_B_PIN = 23;

// ORIGINAL PINS Restored (Input-Only, REQUIRES EXTERNAL PULL-UP RESISTORS)
const int IR_A_START = 36; 
const int IR_A_END   = 39; 
const int IR_B_START = 34; 
const int IR_B_END   = 35; 
const int IR_NECK    = 32; // This pin DOES support internal pull-ups

// --- SERIAL PIN CONFIGURATION ---
// Serial2 is used for incoming drop commands (from Jetson/Pi)
const int CMD_RX_PIN = 16;
const int CMD_TX_PIN = 17;

// Serial1 is used for outgoing MAVLink telemetry (to Flight Controller)
const int MAVLINK_RX_PIN = 18;
const int MAVLINK_TX_PIN = 19;

Servo servoA;
Servo servoB;

// --- SYSTEM STATE VARIABLES ---
int activeFile = 1;
int targetAngle = 15;
unsigned long openTimeMs = 1000;

unsigned long dropStartTime = 0;
bool isDropping = false;
bool dropCommandReceived = false;
bool dropConfirmed = false;

unsigned long lastTestTrigger = 0;
const unsigned long testIntervalMs = 5000;

// Jamming State Flags
bool isSystemJammed = false;
String jamAlertMessage = "";

void setup() {
  // USB Debugging
  Serial.begin(115200);
  
  // UART for incoming drop commands (from onboard computer)
  Serial2.begin(115200, SERIAL_8N1, CMD_RX_PIN, CMD_TX_PIN);

  // UART for outgoing MAVLink (to Drone Flight Controller)
  Serial1.begin(57600, SERIAL_8N1, MAVLINK_RX_PIN, MAVLINK_TX_PIN);

  // 1. Initialize Servos
  servoA.attach(SERVO_A_PIN);
  servoB.attach(SERVO_B_PIN);
  servoA.write(0);
  servoB.write(0);

  // 2. Initialize Original IR Pins 
  // NOTE: 34, 35, 36, 39 use standard INPUT. You must wire external resistors!
  pinMode(IR_A_START, INPUT);
  pinMode(IR_A_END, INPUT);
  pinMode(IR_B_START, INPUT);
  pinMode(IR_B_END, INPUT);
  pinMode(IR_NECK, INPUT_PULLUP); // 32 can safely use internal

  Serial.println("System Ready. UART MAVLink Active (57600 baud).");
}

void loop() {
  handleUART();
  handleAutoTrigger();
  handleDropSequence();
  handleMavlink();
}

// ==========================================
// LOGIC FUNCTIONS
// ==========================================

void handleAutoTrigger() {
  if (millis() - lastTestTrigger >= testIntervalMs && !isDropping) {
    lastTestTrigger = millis();
    dropCommandReceived = true;
    Serial.println("\n--- AUTO TEST TRIGGER ---");
  }
}

void handleUART() {
  if (Serial2.available()) {
    String input = Serial2.readStringUntil('\n');
    int commaIndex = input.indexOf(',');
    if (commaIndex != -1 && !isDropping) {
      targetAngle = input.substring(0, commaIndex).toInt();
      openTimeMs = input.substring(commaIndex + 1).toInt();
      dropCommandReceived = true; 
      lastTestTrigger = millis(); 
      
      Serial.print("UART Command Received! New Angle: ");
      Serial.print(targetAngle);
      Serial.println(" degrees.");
    }
  }
}

void handleDropSequence() {
  unsigned long currentMillis = millis();

  if (dropCommandReceived && !isDropping) {
    isDropping = true;
    dropCommandReceived = false;
    dropConfirmed = false;
    dropStartTime = currentMillis;

    if (activeFile == 1) {
      servoA.write(targetAngle);
      Serial.print("Servo A opening to ");
    } else {
      servoB.write(targetAngle);
      Serial.print("Servo B opening to ");
    }
    Serial.println(targetAngle);
  }

  if (isDropping) {
    if (digitalRead(IR_NECK) == LOW) {
      dropConfirmed = true;
    }
    if (currentMillis - dropStartTime >= openTimeMs) {
      servoA.write(0); 
      servoB.write(0); 
      isDropping = false;
      Serial.println("Gate Closed.");
      
      evaluateJamLogic();
    }
  }
}

void evaluateJamLogic() {
  if (dropConfirmed) {
    Serial.println("Status: Drop successful.");
    return;
  }

  if (activeFile == 1) {
    if (digitalRead(IR_A_END) == LOW || digitalRead(IR_A_START) == LOW) {
      Serial.println("FAULT: File A Jammed. Switching to File B.");
      activeFile = 2;
      isSystemJammed = true;
      jamAlertMessage = "WARNING: FILE A JAMMED";
    } else {
      Serial.println("STATUS: File A Empty. Switching to File B.");
      activeFile = 2;
    }
  }
  else if (activeFile == 2) {
    if (digitalRead(IR_B_END) == LOW || digitalRead(IR_B_START) == LOW) {
      Serial.println("CRITICAL FAULT: File B Jammed. Module disabled.");
      isSystemJammed = true;
      jamAlertMessage = "CRITICAL: FILE B JAMMED";
    } else {
      Serial.println("STATUS: Module completely empty.");
    }
  }
}

// ==========================================
// MAVLINK TELEMETRY FUNCTIONS (UART VERSION)
// ==========================================

void handleMavlink() {
  if (isSystemJammed) {
    // Broadcast jamming alert every 2 seconds via UART
    if (millis() - lastMavlinkTime > 2000) {
      send_jamming_alert(jamAlertMessage.c_str());
      lastMavlinkTime = millis();
      Serial.println("MAVLink Sent via Wire: " + jamAlertMessage); 
    }
  } else {
    // Broadcast normal heartbeat every 1 second via UART
    if (millis() - lastMavlinkTime > 1000) {
      send_heartbeat();
      lastMavlinkTime = millis();
    }
  }
}

void send_jamming_alert(const char* alertText) {
  mavlink_message_t msg;
  uint8_t buf[MAVLINK_MAX_PACKET_LEN];

  mavlink_msg_statustext_pack(SYSTEM_ID, COMPONENT_ID, &msg, MAV_SEVERITY_CRITICAL, alertText);
  uint16_t len = mavlink_msg_to_send_buffer(buf, &msg);
  
  // Send the payload down the physical wire
  Serial1.write(buf, len);
}

void send_heartbeat() {
  mavlink_message_t msg;
  uint8_t buf[MAVLINK_MAX_PACKET_LEN];

  mavlink_msg_heartbeat_pack(SYSTEM_ID, COMPONENT_ID, &msg, MAV_TYPE_QUADROTOR, MAV_AUTOPILOT_PX4, MAV_MODE_FLAG_SAFETY_ARMED, 0, MAV_STATE_ACTIVE);
  uint16_t len = mavlink_msg_to_send_buffer(buf, &msg);
  
  // Send the payload down the physical wire
  Serial1.write(buf, len);
}

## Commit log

2026-06-05 Add all project files
    [00_FULL-ASSEMBLY.f3z, 01_HOPPER.dxf, 01_HOPPER.f3d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]
2026-06-05 Create comprehensive master README combining all folder documentation with CAD and analysis visualizations
